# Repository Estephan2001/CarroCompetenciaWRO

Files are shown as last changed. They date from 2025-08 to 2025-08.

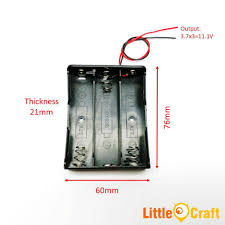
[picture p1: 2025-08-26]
Modelos/3pack18650.jpeg

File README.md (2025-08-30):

# CarroCompetenciaWRO

Este repositorio contiene todo el código, modelos 3D, documentación y resultados del proyecto del **Carro de Competencia WRO**, un robot móvil diseñado para competencias de robótica.

---

## 📂 Contenido del Repositorio

- **Impresiones/**  
  Archivos STL exportados desde Autodesk Inventor para impresión 3D de las piezas del robot.

- **Modelos/**  
  Archivos de diseño CAD realizados en **Autodesk Inventor** (`.ipt`, `.iam`, `.stp`, etc.).

- **Programación/CarroCompetenciaWRO/**  
  Código fuente en C/C++ para Arduino Nano, incluyendo el control de motores, sensores y lógica de navegación.

- **README.md**  
  Documento de presentación y guía de uso del proyecto.

---

## 🤖 Descripción del Proyecto

El **CarroCompetenciaWRO** es un prototipo robotizado construido para competencias (como la World Robot Olympiad), con las siguientes características destacadas:

- **Diseño 100% propio**, modelado en **Autodesk Inventor** aplicando principios de ingeniería.  
- **Fabricación por impresión 3D en PLA**, logrando piezas ligeras, resistentes y fáciles de modificar.  
- **Sistema de movilidad**: motorreductores controlados con **L298N** para las ruedas traseras.  
- **Dirección**: servos SG90 para las ruedas delanteras.  
- **Orientación y giros**: **MPU6050** utilizando el eje *yaw* para conteo de vueltas.  
- **Sensores**:  
  - **Ultrasónicos** (frontal y laterales) para evitar colisiones.  
  - **Sensor de color** para detección de obstáculos y zonas de decisión.  
  - **Sensores de línea** para conteo de vueltas o trayectorias.  
- **Control central**: **Arduino Nano**, montado en una placa de pruebas.  
- **Energía**: batería recargable como fuente de poder.  

---

## ⚙️ Justificación de Componentes

| Componente | Función | Razón de elección |
|---|---|---|
| **Inventor + PLA** | Diseño y fabricación de piezas mecánicas | Permite diseño preciso, prototipado rápido y ajustes iterativos. |
| **Motorreductores + L298N** | Propulsión de ruedas traseras | Ofrece buen torque y control de dirección/velocidad con un solo driver. |
| **Servos SG90** | Dirección de ruedas delanteras | Compactos, precisos, de bajo consumo y fáciles de usar. |
| **MPU6050 (yaw)** | Conteo de vueltas mediante medición de orientación | Sensor económico y confiable para medir rotación en el eje yaw. |
| **Sensores ultrasónicos** | Detección de obstáculos adelante y a los lados | Económicos, con buen rango de detección para navegación segura. |
| **Sensor de color** | Reconocimiento de obstáculos o zonas por color | Permite decisiones basadas en señales visuales. |
| **Sensores de línea** | Conteo de vueltas o seguimiento de pista | Brindan precisión en trayectorias repetitivas. |
| **Placa de pruebas + Nano** | Integración y control | Plataforma accesible y ampliamente soportada para coordinar sensores y actuadores. |
| **Batería** | Fuente de energía | Alimenta todo el sistema de forma autónoma. |

---

## 🚀 Instrucciones para Empezar

### 1. Clonar el repositorio  
```sh
git clone https://github.com/Estephan2001/CarroCompetenciaWRO.git

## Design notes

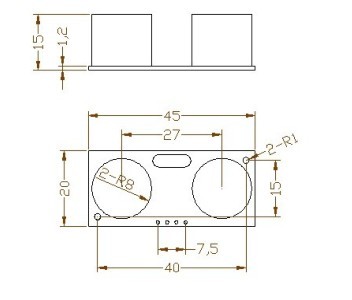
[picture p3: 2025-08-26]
Modelos/Ultrasonido.jpeg

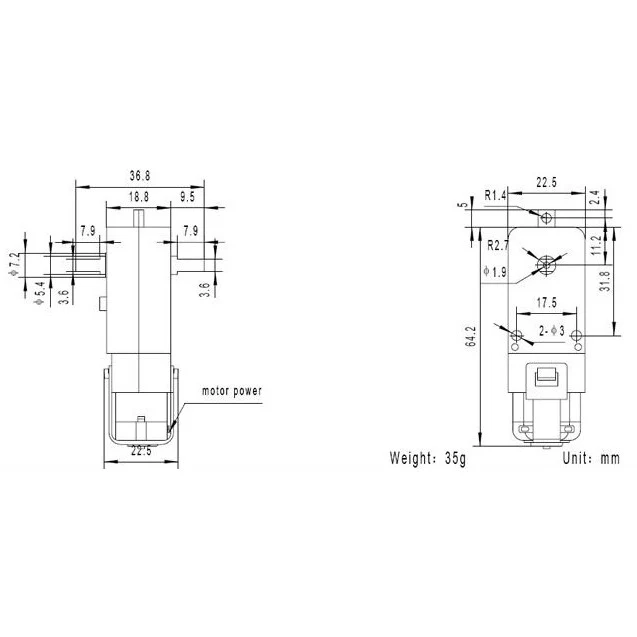
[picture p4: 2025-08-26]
Modelos/Motorreductor.webp

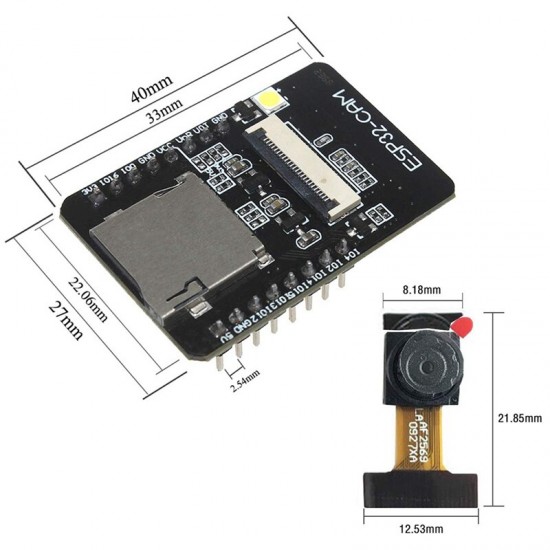
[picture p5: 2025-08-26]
Modelos/ESP32CAM.jpg

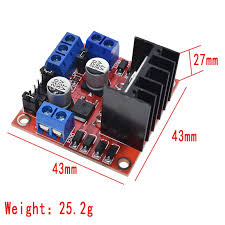
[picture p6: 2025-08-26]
Modelos/L298N.jpeg

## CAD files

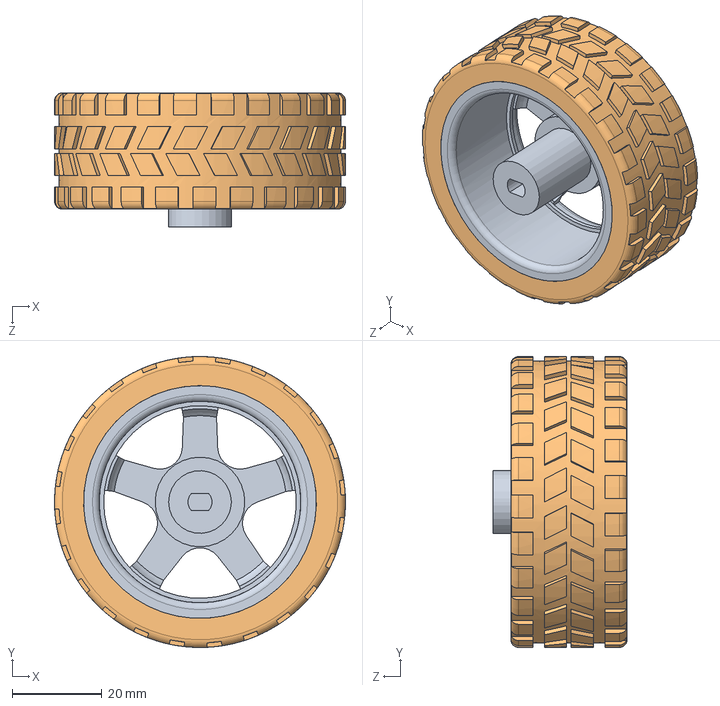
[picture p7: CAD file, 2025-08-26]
Modelos/Motorreductor/Rueda ensamblada.SLDASM
65.0 x 65.0 x 30.0 mm
Rueda
Neumatico

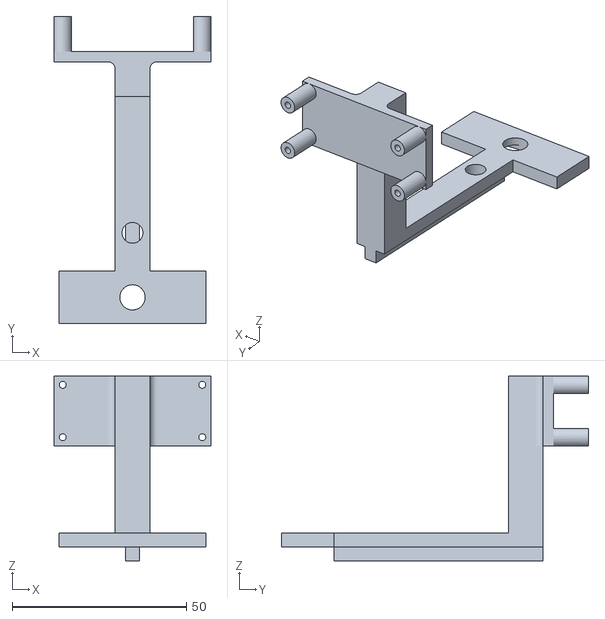
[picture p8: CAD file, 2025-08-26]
Impresiones/2xSujetadorUltrasonico2.stl
45.0 x 88.0 x 53.0

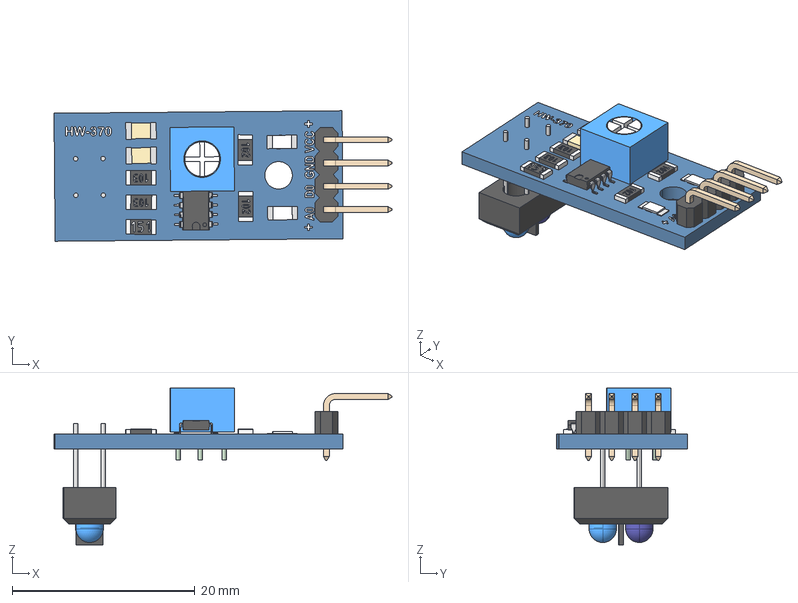
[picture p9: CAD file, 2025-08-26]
Modelos/TCRT5000.stp
37.0 x 14.3 x 17.1 mm
TCRT5000
leds Geometry
pin
IC_smd_8
smd_10k Geometry x 2
cover x 2
smd_150 Geometry
cover2
Surf Geometry x 2
cover3 x 2
LED_SMD x 2
smd_1k Geometry x 2
cover4 x 2
pot Geometry
pin2
leds2 Geometry
pins
Board Geometry
TXT
4PinsOut Geometry
pin3

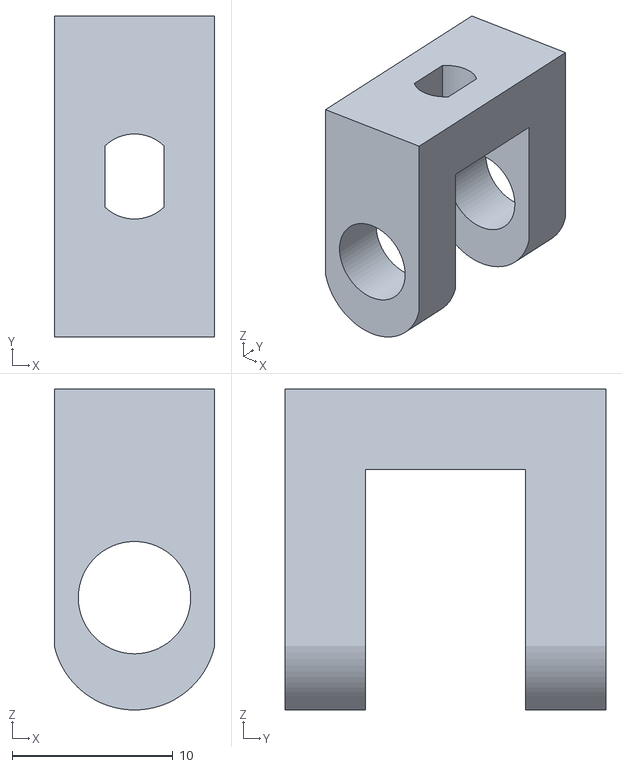
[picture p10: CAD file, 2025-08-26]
Impresiones/2xSoporteEjeRuedas.stl
10.0 x 20.0 x 20.0

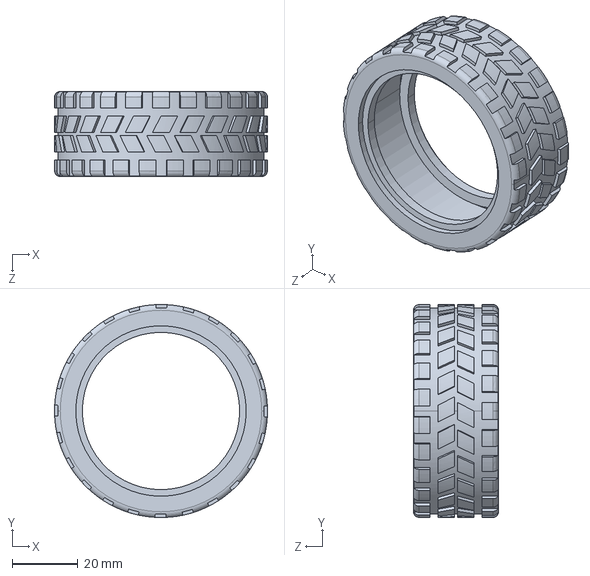
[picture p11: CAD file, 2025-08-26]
Modelos/Motorreductor/Neumatico.STEP
65.0 x 65.0 x 26.0 mm

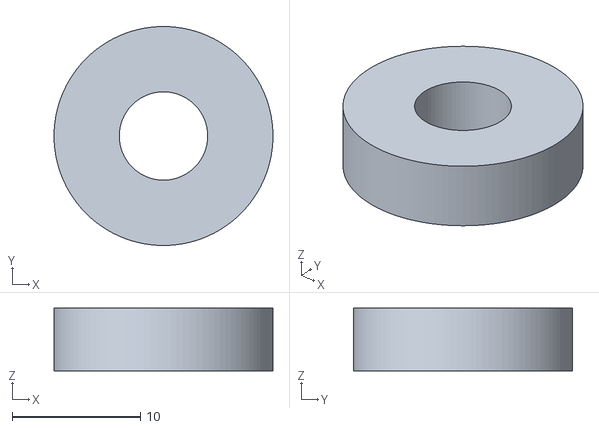
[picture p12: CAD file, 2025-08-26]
Impresiones/2xSeguroPinRuedas2.stl
17.1 x 17.1 x 4.90

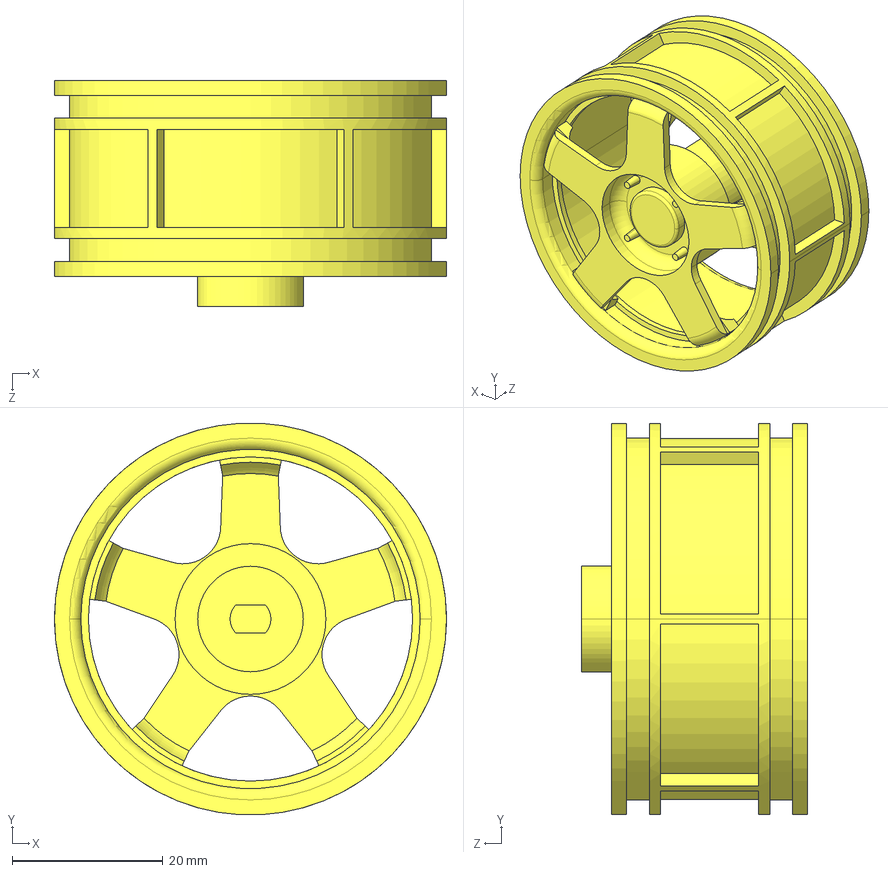
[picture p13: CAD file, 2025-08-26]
Modelos/Motorreductor/Rueda.STEP
52.0 x 51.9 x 30.0 mm

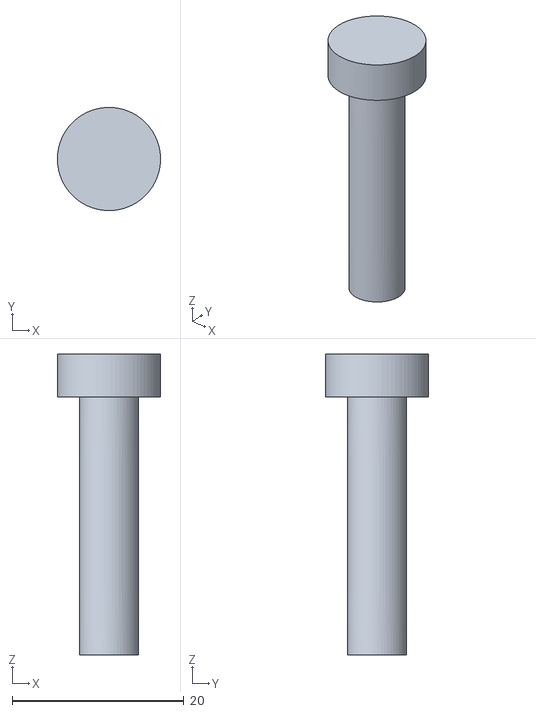
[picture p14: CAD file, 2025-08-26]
Impresiones/PinRuedas2.stl
12.0 x 12.0 x 35.0

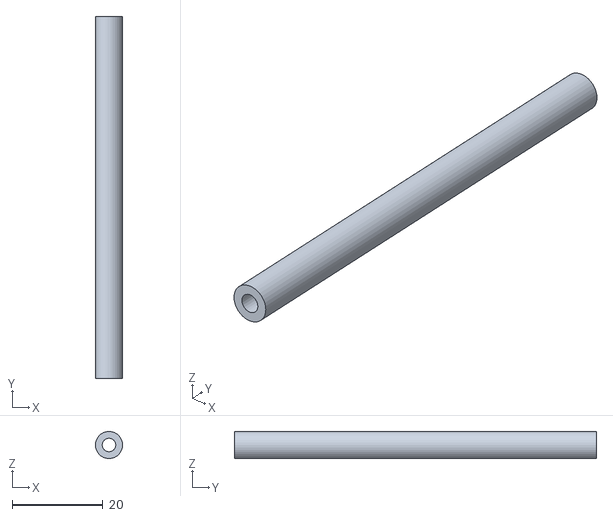
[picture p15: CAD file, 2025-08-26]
Impresiones/4xPOSTES.stl
6.00 x 80.0 x 5.97

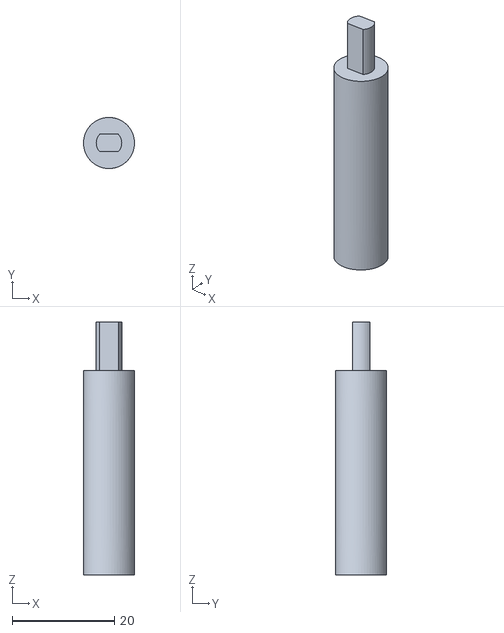
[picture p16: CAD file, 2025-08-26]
Impresiones/2xejellantasdeatras.stl
10.0 x 10.00 x 49.5

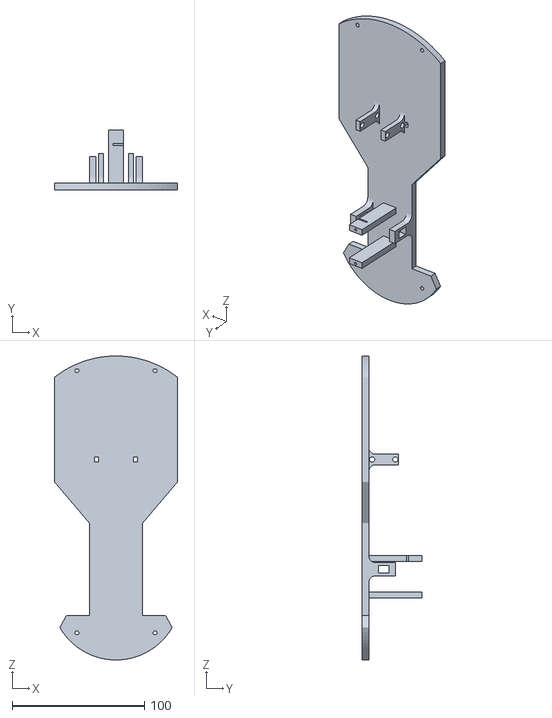
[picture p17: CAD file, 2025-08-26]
Impresiones/BASE DE CARO.stl
93.0 x 45.0 x 229.7

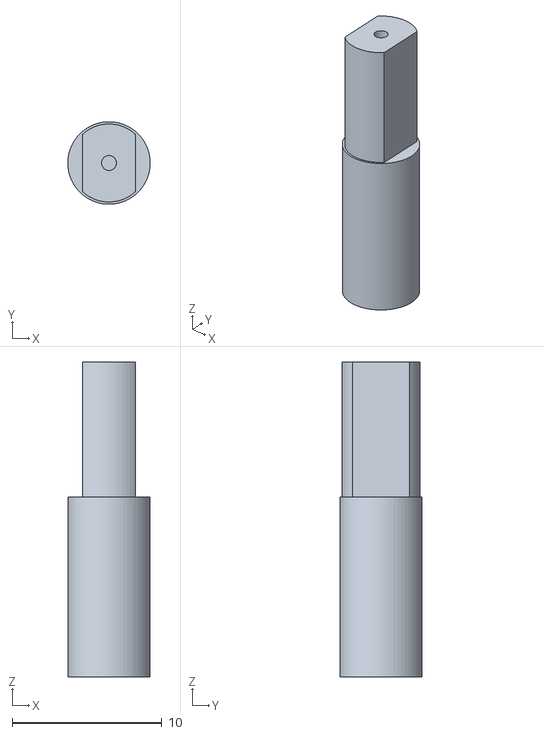
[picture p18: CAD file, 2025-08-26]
Impresiones/2xPinRuedas.stl
5.50 x 5.49 x 21.0

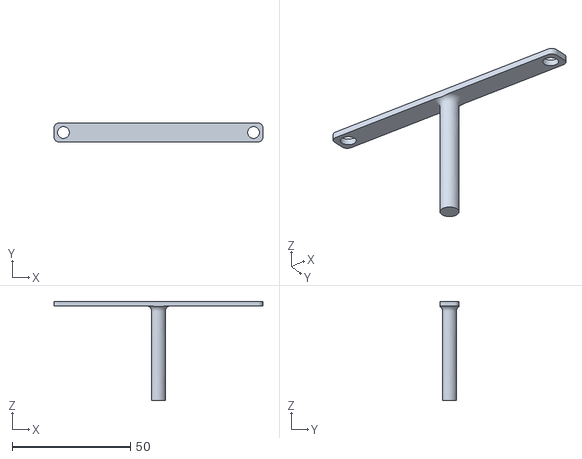
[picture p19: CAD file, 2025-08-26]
Impresiones/SoportesDireccion.stl
88.4 x 8.00 x 42.0

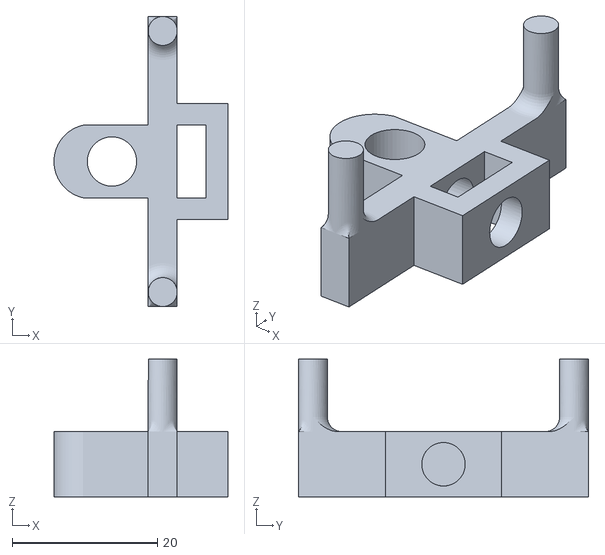
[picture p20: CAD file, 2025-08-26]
Impresiones/2xejedemovimiento.stl
24.0 x 40.0 x 19.0

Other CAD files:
Impresiones/2xPinRuedas2.stl
Impresiones/BASE NIVEL 2.stl
Impresiones/ejellantasdelante.stl
Impresiones/2xSeguroPinRueda.stl
Impresiones/DireccionTimon.stl
Modelos/Motorreductor/Neumatico.SLDPRT
Modelos/Motorreductor/Neumatico/Neumatico.ipt
Modelos/Motorreductor/Rueda.SLDPRT
Modelos/TCRT5000/4PinsOut Geometry.ipt
Modelos/TCRT5000/4PinsOut.iam
Modelos/TCRT5000/Board Geometry.ipt
Modelos/TCRT5000/Board.iam
Modelos/TCRT5000/IC_smd_8.ipt
Modelos/TCRT5000/LED_SMD.ipt
Modelos/TCRT5000/Surf Geometry.ipt
Modelos/TCRT5000/Surf.iam
Modelos/TCRT5000/Surf_1.iam
Modelos/TCRT5000/TCRT5000.iam
Modelos/TCRT5000/TCRT5000.ipt
Modelos/TCRT5000/TXT.ipt
Modelos/TCRT5000/cover.ipt
Modelos/TCRT5000/cover2.ipt
Modelos/TCRT5000/cover3.ipt
Modelos/TCRT5000/cover4.ipt
Modelos/TCRT5000/leds Geometry.ipt
Modelos/TCRT5000/leds.iam
Modelos/TCRT5000/leds2 Geometry.ipt
Modelos/TCRT5000/leds2.iam
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

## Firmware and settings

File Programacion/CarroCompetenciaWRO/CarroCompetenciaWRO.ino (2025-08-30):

// Librerías

#include "FEPO.h"
#include <Servo.h>
#include "UltraSonicoSM.h"
#include "ValorReferenciaSM.h"

// Constantes (Definimos en dónde conectamos todo)
#define ServoDireccionPin 2
#define ServoUltrasonicoAdelantePin 10
#define ServoUltrasonicoAtrasPin 9
// Pines de ultrasonicos
#define TriggerUltrasonicoAtras 11
#define EchoUltrasonicoAtras 3
#define TriggerUltrasonicoAdelante 6
#define EchoUltrasonicoAdelante 7
#define TriggerUltrasonicoObstaculo 5
#define EchoUltrasonicoObstaculo 4
#define TiempoEntrePosiciones 20  //ms
//Pines de Seguidores de línea analogos
#define SeguidorIzquierda A6
#define SeguidorDerecha A7
//Pines sensor color
#define PinSalidaColor 8
#define PinS0 A0
#define PinS1 A1
#define PinS2 A2
#define PinS3 A3
// Pines Motor propulsor
#define InputMotor1 12
#define InputMotor2 13


// Definir Objetos
Servo ServoDireccion;            // Creamos un objeto servo
Servo ServoUltrasonicoAdelante;  // Creamos un objeto servo
Servo ServoUltrasonicoAtras;     // Creamos un objeto servo

// Variables Robot

// Posiciones actuales Servo
int PosServoDireccion{ 90 };
int MinServoDireccion{ 70 };
int MaxServoDireccion{ 125 };
int PosServoUltrasonicoAdelante{ 90 };
int PosServoUltrasonicoAtras{ 90 };

// Variables Sensores
char LadoGiro{};  // I C D (Izquierda Centro Derecha)

char Color{};  // R V A (Rojo Verde Azul)
int Rojo{};
int Verde{};
int Azul{};
int UMBRAL_DIF = 15;  // Diferencia mínima entre componentes para decidir
int MIN_VAL = 20;     // Valor mínimo válido para considerar un color
int MAX_VAL = 255;    // Valor máximo válido (dependerá de tu sensor)

char DireccionCarro{};  // A B P(Adeltante o Atras o Parar)
int AnguloActual{};     // Valor de MPU6050 o giroscopio
// Variables donde se guarda la informacion obtenida de los sensores
int DistanciaUltrasonicoDelante{};
int DistanciaUltrasonicoAtras{};
int DistanciaUltrasonicoObstaculo{};
int ValorLineaIzquierda{};
int ValorLineaDerecha{};
float ContadorVueltas{};
int PosServoError{};

// Variables de pasos
int Acto{ 0 };
int dir{ 0 };


// Timers
unsigned long TiempoServosPasado{};
int IntervaloEntrePosiciones{ TiempoEntrePosiciones };

// Timer Mediciones
unsigned long TiempoPasadoMediciones{};
int IntervaloMediciones{ 1 };

// Condiciones de inicio Robot
int DistanciaInicialParedUltrasonicoAdelante{};
int DistanciaInicialParedUltrasonicoAtras{};
int ErrorDistanciaAdelante{};
int ErrorDistanciaAtras{};

// Variables para contar vueltas
float AnguloPrevio = 0;     // Ángulo en la última medición
long AcumuladorAngulo = 0;  // Total de grados recorridos
//int ContadorVueltas = 0;    // Número de vueltas completadas


// Prototipos de funciones
char detectarColor(int r, int g, int b);


void setup() {

  inicioMPU();
  // Serial.begin(9600);

  ServoDireccion.attach(ServoDireccionPin);                      // Pin donde está conectado el servo (PWM)
  ServoUltrasonicoAdelante.attach(ServoUltrasonicoAdelantePin);  // Pin donde está conectado el servo (PWM)
  ServoUltrasonicoAtras.attach(ServoUltrasonicoAtrasPin);        // Pin donde está conectado el servo (PWM)
  //Posiciones iniciales
  ServoDireccion.write(PosServoDireccion);
  ServoUltrasonicoAdelante.write(PosServoUltrasonicoAdelante);
  ServoUltrasonicoAtras.write(PosServoUltrasonicoAtras);

  //Inicializar Ultrasónicos
  init_UltraSonico(TriggerUltrasonicoAtras, EchoUltrasonicoAtras);
  init_UltraSonico(TriggerUltrasonicoAdelante, EchoUltrasonicoAdelante);
  init_UltraSonico(TriggerUltrasonicoObstaculo, EchoUltrasonicoObstaculo);

  //Inicializar Seguidores de línea
  pinMode(SeguidorIzquierda, INPUT);
  pinMode(SeguidorDerecha, INPUT);

  // Sensor Color
  pinMode(PinS0, OUTPUT);
  pinMode(PinS1, OUTPUT);
  pinMode(PinS2, OUTPUT);
  pinMode(PinS3, OUTPUT);
  pinMode(PinSalidaColor, INPUT);
  digitalWrite(PinS0, HIGH);
  digitalWrite(PinS1, HIGH);

  // Inicializar Motor
  pinMode(InputMotor1, OUTPUT);
  pinMode(InputMotor2, OUTPUT);
  analogWrite(InputMotor1, 0);
  analogWrite(InputMotor2, 0);

  pinMode(0, INPUT_PULLUP);

  // BOTONES CONTROL
  bool inicio{ true };
  while (inicio) {
    if (digitalRead(1) == LOW) {
      LadoGiro = 'I';
      inicio = false;
      int MinServoDireccion{ 70 };
      int MaxServoDireccion{ 125 };
    }
    if (digitalRead(0) == LOW) {
      LadoGiro = 'D';
      inicio = false;
      int MinServoDireccion{ 125 };
      int MaxServoDireccion{ 70 };
    }
  }

  // Aquí decidimos con los botones a dónde irá el robot (Izquierda o derecha)


  // Sentencia para escoger lado (Botones)

  DireccionCarro = 'P';
  PosServoDireccion = 97;
  Acto = 0;  //Calibraciones iniciales
}

void loop() {

  // Poner posicion deseada de los servos según el giro
  if (LadoGiro == 'I') {

    PosServoUltrasonicoAdelante = 180;
    PosServoUltrasonicoAtras = 0;
    ServoUltrasonicoAdelante.write(PosServoUltrasonicoAdelante);
    ServoUltrasonicoAtras.write(PosServoUltrasonicoAtras);
    delay(2000);
    LadoGiro = 0;


  } else if (LadoGiro == 'D') {

    PosServoUltrasonicoAdelante = 0;
    PosServoUltrasonicoAtras = 180;
    ServoUltrasonicoAdelante.write(PosServoUltrasonicoAdelante);
    ServoUltrasonicoAtras.write(PosServoUltrasonicoAtras);
    delay(2000);
    LadoGiro = 0;

  } else if (LadoGiro == 'C') {
    PosServoUltrasonicoAdelante = 90;
    PosServoUltrasonicoAtras = 90;
    ServoUltrasonicoAdelante.write(PosServoUltrasonicoAdelante);
    ServoUltrasonicoAtras.write(PosServoUltrasonicoAtras);
    delay(2000);
    LadoGiro = 0;
  }

  // Posicionar servos según sea la necesidad
  if (millis() >= TiempoServosPasado + IntervaloEntrePosiciones) {
    ServoDireccion.write(PosServoDireccion);
    TiempoServosPasado = millis();
  }

  // El Robot Se mueva a adelante, atras o pare.
  if (DireccionCarro == 'A') {
    analogWrite(InputMotor1, 150);
    analogWrite(InputMotor2, 0);
  } else if (DireccionCarro == 'B') {
    analogWrite(InputMotor1, 0);
    analogWrite(InputMotor2, 150);
  } else if (DireccionCarro == 'P') {
    analogWrite(InputMotor1, 0);
    analogWrite(InputMotor2, 0);
  }

  // Mediciones
  // Angulo de carro
  // Medir Angulos
  mpuupdate();
  AnguloActual = yaw;

  if (millis() >= TiempoPasadoMediciones + IntervaloMediciones) {
    //UltraSonico

    DistanciaUltrasonicoDelante = Distancia_UltraSonico(TriggerUltrasonicoAdelante, EchoUltrasonicoAdelante);
    //DistanciaUltrasonicoAtras = Distancia_UltraSonico(TriggerUltrasonicoAtras, EchoUltrasonicoAtras);
    //DistanciaUltrasonicoObstaculo = Distancia_UltraSonico(TriggerUltrasonicoObstaculo, EchoUltrasonicoObstaculo);

    // Medicion de Color
    /*
    digitalWrite(PinS2, LOW);
    digitalWrite(PinS3, LOW);
    Rojo = pulseIn(PinSalidaColor, digitalRead(PinSalidaColor) == HIGH ? LOW : HIGH);
    digitalWrite(PinS3, HIGH);
    Azul = pulseIn(PinSalidaColor, digitalRead(PinSalidaColor) == HIGH ? LOW : HIGH);
    digitalWrite(PinS2, HIGH);
    Verde = pulseIn(PinSalidaColor, digitalRead(PinSalidaColor) == HIGH ? LOW : HIGH);
    // Determinar Color
    Color = detectarColor(Rojo, Verde, Azul);
*/

    TiempoPasadoMediciones = millis();
  }


  //////////////////////////////////////////////////////////////////////////////////////////// Procedimiento para RETO 1 ///////////////////////////////////////////////////////////////////////////



  /*

  int DistanciaUltrasonicoDelante{};
int DistanciaUltrasonicoAtras{};
int DistanciaUltrasonicoObstaculo{};
int ValorLineaIzquierda{};
int ValorLineaDerecha{};

int DistanciaParedUltrasonicoAdelante{};
int DistanciaParedUltrasonicoAtras{};

ContadorVueltas

int ErrorDistanciaAdelante{};
int ErrorDistanciaAtras{};
*/
  if (Acto == 0) {  // Registras las condiciones iniciales
    //Serial.println("Acto 1");
    DireccionCarro = 'A';
    DistanciaUltrasonicoDelante = Distancia_UltraSonico(TriggerUltrasonicoAdelante, EchoUltrasonicoAdelante) + 10;  ////////////MODIFICAR SI SE QUIERE SEPARAR DE LA PARED
    DistanciaInicialParedUltrasonicoAdelante = DistanciaUltrasonicoDelante;
    DistanciaInicialParedUltrasonicoAtras = DistanciaUltrasonicoAtras;
    ServoDireccion.write(97);
    Acto = 1;
  }
  ////////////////**************************************************************************************************************************************************************************************
  else if (Acto == 1) {
    // Contar las vueltas

    ContadorVueltas = abs(angleZ / 360);
    // Serial.println(angleZ);
    if (ContadorVueltas >= 7.8) {  ////MODIFICAR SI LO COMPLETA LAS VUELTAS
      DireccionCarro = 'P';
      Acto = 2;
    }
    //////////////////////////////////**********************************************************************************************************************************************************************
    // Que se mantenga a cierta distancia


    float errorDistancia{};
    errorDistancia = (DistanciaUltrasonicoDelante - DistanciaInicialParedUltrasonicoAdelante) * 20;  //// 20 - 30 SI REACCIONA MUY LENTO
    int PosServoError = map(errorDistancia, 20, -20, MinServoDireccion, MaxServoDireccion);

    /*if (dir == 1) {
      int PosServoError = map(errorDistancia, 20, -20, MaxServoDireccion, MinServoDireccion);
    }

    if (dir == 2) {
      int PosServoError = map(errorDistancia, 20, -20, MinServoDireccion, MaxServoDireccion);
    }*/
    if (PosServoError > MaxServoDireccion) PosServoError = MaxServoDireccion;
    if (PosServoError < MinServoDireccion) PosServoError = MinServoDireccion;
    PosServoDireccion = PosServoError;
    ServoDireccion.write(PosServoDireccion);

    ///////////**********************************************************************************************************************************************************
  }
}

// Funciones EXTRA

char detectarColor(int r, int g, int b) {
  // Si los valores son muy bajos, consideramos que no hay color válido
  if (r < MIN_VAL && g < MIN_VAL && b < MIN_VAL) {
    return '?';  // Sin detección
  }

  // Diferencias entre componentes
  int difRG = r - g;
  int difRB = r - b;
  int difGB = g - b;

  // --- Clasificación básica ---
  if ((r > b + UMBRAL_DIF) && (r > g)) {
    return 'A';  // Rojo
  } else if ((b > r + UMBRAL_DIF) && (b > g)) {
    return 'V';  // Azul
  } else if ((g > r + UMBRAL_DIF) && (g > b)) {
    return 'R';  // Verde (extra ejemplo)
  } else {
    return '?';  // Indefinido o mezcla
  }
}

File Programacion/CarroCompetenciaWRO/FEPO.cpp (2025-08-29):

/* Librería creada por: Estephan Portales
 * Basada en librerías existentes para MPU6050
 */

#include "FEPO.h"
#include <Wire.h>  // Comunicación I2C
#include <EEPROM.h>

float gyroXoffset, gyroYoffset, gyroZoffset;  // offsets del giroscopio
float temp, accX, accY, accZ, gyroX, gyroY, gyroZ;
float angleGyroX, angleGyroY, angleGyroZ;
float angleAccX, angleAccY;
float angleX, angleY, angleZ;
float roll, pitch, yaw;

// Para integración temporal
unsigned long preintervalo1 = 0;

// Prototipos
void inicioMPU();
void MPUwrite(byte reg, byte data);
byte MPUread(byte reg);
void calcoffset(bool console);
void mpuupdate();

void inicioMPU() {
  Wire.begin();          // iniciamos I2C
  MPUwrite(0x19, 0x00);  // SMPLRT_DIV
  MPUwrite(0x1a, 0x00);  // CONFIG
  MPUwrite(0x1b, 0x08);  // GYRO_CONFIG (+/- 500 deg/s)
  MPUwrite(0x1c, 0x00);  // ACCEL_CONFIG (+/- 2g)
  MPUwrite(0x6b, 0x01);  // PWR_MGMT_1
  
  preintervalo1 = millis();
  calcoffset(true);
}

void MPUwrite(byte reg, byte data) {
  Wire.beginTransmission(0x68);
  Wire.write(reg);
  Wire.write(data);
  Wire.endTransmission();
}

byte MPUread(byte reg) {
  Wire.beginTransmission(0x68);
  Wire.write(reg);
  Wire.endTransmission(true);
  Wire.requestFrom(0x68, 1);
  return Wire.read();
}

void calcoffset(bool console) {
  float x = 0, y = 0, z = 0;
  int16_t rx, ry, rz;

  delay(1000);

  for (int i = 1; i <= 3000; i++) {
    Wire.beginTransmission(0x68);
    Wire.write(0x43);  // registro giroscopio X
    Wire.endTransmission(false);
    Wire.requestFrom((int)0x68, 6);

    rx = Wire.read() << 8 | Wire.read();
    ry = Wire.read() << 8 | Wire.read();
    rz = Wire.read() << 8 | Wire.read();

    x += ((float)rx)/65.5;
    y += ((float)ry)/65.5;
    z += ((float)rz)/65.5;
  }

  gyroXoffset = x / 3000.0;
  gyroYoffset = y / 3000.0;
  gyroZoffset = z / 3000.0;

  if(console){
    Serial.println("Offsets calculados:");
    Serial.print("X: "); Serial.println(gyroXoffset);
    Serial.print("Y: "); Serial.println(gyroYoffset);
    Serial.print("Z: "); Serial.println(gyroZoffset);
  }
}

void mpuupdate() {
  int16_t rawAccX, rawAccY, rawAccZ, rawTemp;
  int16_t rawGyroX, rawGyroY, rawGyroZ;

  Wire.beginTransmission(0x68);
  Wire.write(0x3B);  // primer registro a leer
  Wire.endTransmission(false);
  Wire.requestFrom((int)0x68, 14);

  rawAccX = Wire.read() << 8 | Wire.read();
  rawAccY = Wire.read() << 8 | Wire.read();
  rawAccZ = Wire.read() << 8 | Wire.read();
  rawTemp = Wire.read() << 8 | Wire.read();
  rawGyroX = Wire.read() << 8 | Wire.read();
  rawGyroY = Wire.read() << 8 | Wire.read();
  rawGyroZ = Wire.read() << 8 | Wire.read();

  // Conversión
  temp = (rawTemp + 12412.0)/340.0;
  accX = ((float)rawAccX)/16384.0;
  accY = ((float)rawAccY)/16384.0;
  accZ = ((float)rawAccZ)/16384.0;

  // Ángulos acelerómetro
  angleAccX = atan2(accY, sqrt(accZ*accZ + accX*accX))*180.0/PI;
  angleAccY = atan2(accX, sqrt(accZ*accZ + accY*accY))*-180.0/PI;

  // Giroscopio
  gyroX = ((float)rawGyroX)/65.5 - gyroXoffset;
  gyroY = ((float)rawGyroY)/65.5 - gyroYoffset;
  gyroZ = ((float)rawGyroZ)/65.5 - gyroZoffset;

  // Delta tiempo en segundos
  static unsigned long lastMicros = micros();
  float dt = (micros() - lastMicros)/1000000.0;
  lastMicros = micros();

  // Integración giroscopio
  angleGyroX += gyroX * dt;
  angleGyroY += gyroY * dt;
  angleGyroZ += gyroZ * dt;

  // Filtro complementario para roll y pitch
  float alpha = 0.98;  // 0.98 giroscopio / 0.02 acelerómetro
  angleX = alpha * (angleX + gyroX*dt) + (1-alpha) * angleAccX;
  angleY = alpha * (angleY + gyroY*dt) + (1-alpha) * angleAccY;

  // Yaw acumulado (sin normalizar)
  static float yaw_suave = 0;
  yaw_suave = alpha * (yaw_suave + gyroZ*dt) + (1-alpha) * yaw_suave;
  yaw = yaw_suave;

  // Salida
  roll = angleX;
  pitch = angleY;
  angleZ = angleGyroZ; // para uso directo si quieres acumular giros
}

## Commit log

2025-08-26 Programacion Servo
2025-08-26 Configuracion servos
2025-08-26 Seguidores de línea
2025-08-26 Sensor Color
2025-08-26 Configuracion Motores
2025-08-27 Giro Servos Fallida
2025-08-29 Contador de vueltas
